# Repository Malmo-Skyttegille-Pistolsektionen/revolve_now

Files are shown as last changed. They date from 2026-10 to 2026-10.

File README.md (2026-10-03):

# Revolve Now

Software for running timed shooting programs on a rotating target system, built
by and for Malmö Skyttegille Pistolsektionen.

An ESP32-S3 board turns the targets face-on and edge-on to a shooting program
and plays the spoken range commands over an amplifier. A React web app — served
by the board itself over WiFi — starts and stops programs, follows the run live
over Server-Sent Events, and manages the stored programs and audio.

<p align="center">
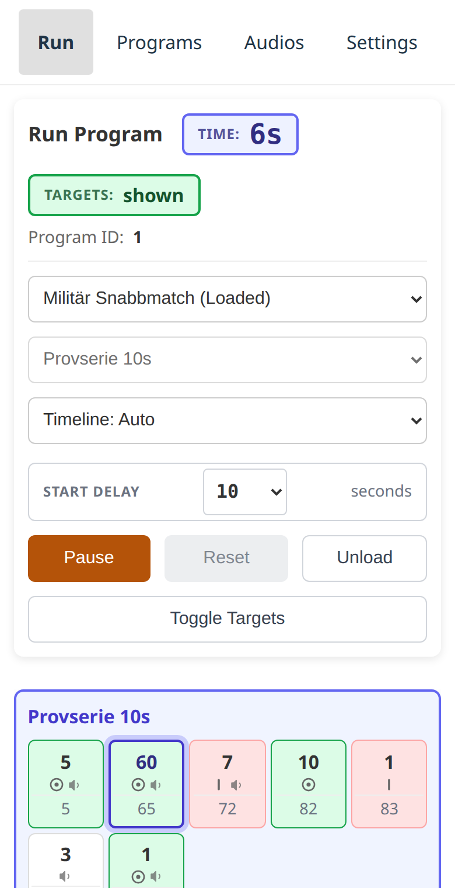
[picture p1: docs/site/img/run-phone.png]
The Run page on a phone, partway through a program
  
</p>

## ⚠️ SAFETY WARNING — READ BEFORE INSTALLING OR OPERATING

**This device moves steel on a live firing range, and it moves it on a timer.**
A target turns because a program said it was time, not because it can see who
is in front of it. It has no idea anyone is downrange.

- **The range's own safety rules and range commands govern the line. This
  software governs nothing.** A program running is not a range that is hot; a
  program stopped is not a range that is safe.
- **NEVER go downrange because the web app says the run has finished.** Confirm
  a cease-fire the way your range already requires — verbally, with firearms
  cleared and benched.
- **NEVER leave the device powered while people are forward of the firing
  line** unless your club has decided that is safe and knows what the targets
  do at power-up.
- **A target turning can injure somebody standing next to it.** Keep clear of
  the mechanism whenever the device is powered.

The targets rest **shown** at boot, deliberately: a target that turns of its own
accord when a board is powered is the failure this project is most concerned
with. That resting state can be changed to suit a target system wired the other
way round, but only over a USB cable, never from the web app — see
[Settings](https://malmo-skyttegille-pistolsektionen.github.io/revolve_now/settings/).

**Do not rely on this software to protect anyone.** It is a convenience for
running programs, not a safety device, and it has no interlock, no sensor, and
no way to know where people are.

**LIABILITY DISCLAIMER:** This project is provided as-is with absolutely no
warranty of any kind. The author(s) accept no responsibility or liability for
any injury, damage, or loss resulting from building, installing, modifying, or
operating this system. You build and use it entirely at your own risk.

---

## Documentation

Everything an operator needs is on the documentation site:

- **[Operator documentation](https://malmo-skyttegille-pistolsektionen.github.io/revolve_now/)**
  — wiring, connecting, running a program, settings, and what the status LED is
  telling you. This is the one to send a club member.
- **[Program editor](https://malmo-skyttegille-pistolsektionen.github.io/revolve_now/editor/)**
  — write and edit programs in a browser with **no device attached**, then
  download the file or open a pull request against this repository. Also useful
  for reading a shipped program without a board in front of you.
- **[Hardware and wiring](https://malmo-skyttegille-pistolsektionen.github.io/revolve_now/hardware/)**
  — what a target system has to do to work, the DB9 pinout, and the transistor
  that does the switching.

## Installing

Releases ship a pre-built firmware image; you do not need a toolchain to put it
on a board. See
[Connecting](https://malmo-skyttegille-pistolsektionen.github.io/revolve_now/connecting/)
for getting the device onto your network afterwards, and
[Settings](https://malmo-skyttegille-pistolsektionen.github.io/revolve_now/settings/)
for adapting a stock image to your own board — the target pin, its polarity,
the audio and LED pins and the device's name are all configurable on the
device, without rebuilding it.

## Target systems

- **[Eigenbrod TP2](https://eigenbrod-schiessanlagen.de/en/products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)**
  — what this was built against and what it runs on.

Nothing in the firmware is specific to that system. The board speaks no
proprietary protocol to the targets: it closes and opens **one circuit**, and
the target system's own electronics do the rest. Any system driven the same way
should work.

## Layout

| Directory | Holds |
|---|---|
| [`contracts/`](contracts/README.md) | The canonical API contract: OpenAPI for REST v2, AsyncAPI for SSE v2, the program schema |
| [`firmware/`](firmware/README.md) | The ESP-IDF firmware: target IO, audio, storage, REST + SSE server |
| [`webapp/`](webapp/README.md) | The React front end, embedded in the firmware's application image |
| [`resources/`](resources/README.md) | Shipped programs and audio clips flashed onto the device |
| [`docs/`](docs/) | The [decision log](docs/DECISIONS.md), [how releases are cut](docs/RELEASING.md), and the source of the documentation site |

## Contributing

Building, flashing, running it without a device, and the coding standards are
in [`CONTRIBUTING.md`](CONTRIBUTING.md).

## License

MIT — see [`LICENSE`](LICENSE). It covers everything here except the vendored
libraries under `firmware/lib/`, which keep their own.

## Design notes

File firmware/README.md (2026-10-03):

# Revolve Now firmware — ESP32 (ESP-IDF)

Native ESP-IDF firmware for Malmö Skyttegille Pistolsektionen's
[Eigenbrod TP2 rotation target system](https://eigenbrod-schiessanlagen.de/en/products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).
It runs shooting programs — turning the targets and playing the commands — and
serves the React webapp over REST and Server-Sent Events.

This is the ESP-IDF port of
[`rotation_target_backend_esp32_micropython`](https://github.com/Malmo-Skyttegille-Pistolsektionen/rotation_target_backend_esp32_micropython)
at its API v2 revision. Both speak the same contract; see
[`docs/adr/0001-esp-idf-port.md`](docs/adr/0001-esp-idf-port.md) for why the
port exists.

## Hardware

**ESP32-S3** with 16 MB flash and 8 MB PSRAM — an ESP32-S3-DevKitC-1 N16R8, or
the club's own REVOLVENOW Rev 1 board.

No pin is hardcoded: the target GPIO **and its polarity**, the status LED, and
the I2S pins are all `menuconfig` options, so a different board is a different
`sdkconfig` rather than a source edit.

See [`docs/HARDWARE.md`](docs/HARDWARE.md) for the wiring, the full option list,
the partition layout, and the esptool `--no-stub` quirk you will hit when
flashing these boards.

## Build, flash, test

```bash
git clone https://github.com/Malmo-Skyttegille-Pistolsektionen/revolve_now.git
cd revolve_now/firmware

idf.py set-target esp32s3          # FIRST clone only - see the warning below
idf.py menuconfig                  # optional: seed WiFi under "Revolve Now"
idf.py build
idf.py -p /dev/ttyACM0 flash monitor
```

> ⚠️ **`idf.py set-target` and `idf.py fullclean` destroy `sdkconfig`** — the
> only copy of the WiFi credentials. Use **`idf.py reconfigure`** on a clone you
> have already built. Why, and how to keep the credentials out of the tree
> entirely, in [`CONTRIBUTING.md`](CONTRIBUTING.md).

> **`idf.py flash` uses esptool's stub loader, which fails on this board** and
> fails in a way that looks like bad flash. See
> [`docs/HARDWARE.md`](docs/HARDWARE.md) for the `--no-stub` invocation.

The shipped audio and programs live in the monorepo's sibling `resources/`
directory. The build reads them from there by default; point `RT_RESOURCES_DIR`
elsewhere to override.

The webapp is embedded in the **application image** when `../webapp/dist`
exists, so run `npm run build` in `webapp/` first — see
[*The seams*](../AGENTS.md#the-seams). Because it rides in the app slot, an OTA
updates it along with the firmware (#227); the shipped audio and programs are
still on the filesystem and still do not.

`idf.py flash` no longer touches what has been uploaded to the device: no image
is built for the `userdata` partition at all (#227), so there is nothing to
write over it. The app slot it writes carries the firmware, the web app and the
shipped audio together.

**`partitions.csv` is not a file to change casually** — a table change cannot
go out over the air and wipes NVS, so it costs a cable pass over every board.
See [*Changing the partition table*](CONTRIBUTING.md#changing-the-partition-table).

### WiFi

Credentials live in **NVS**, not in the firmware, so moving the device to a new
network does not need a rebuild. `idf.py flash` leaves the `nvs` partition
alone, so they also survive a firmware update.

If the device cannot join a network — out of the box, or because the range's
WiFi password changed — it brings up a **setup access point** and a captive
portal instead of sitting there unreachable:

1. Join `revolve-now-setup-XXXX` (password: `CONFIG_RT_SETUP_AP_PASSWORD`,
   default `revolvenow`).
2. A setup page should open automatically; if not, browse to
   `http://192.168.4.1`.
3. Enter the network details. The device saves them and restarts.

The Kconfig `RT_WIFI_SSID`/`RT_WIFI_PASSWORD` values are only a first-boot
seed — leave them at the defaults and use the portal, or set them to skip it.
`sdkconfig` is gitignored either way, the same way the MicroPython backend kept
`wifi_credentials.py` out of git.

Once up, the device is at `http://revolve-now.local` (mDNS) or whatever
address it logs on boot.

### Host tests

The run state machine, the program JSON contract, the `stateUpdate` serializer
and the control lock all run on the build machine — no hardware, no sleeps:

```bash
cd host_test && cmake -B build && cmake --build build -j && cd build && ctest --output-on-failure
```

Add `-DRT_COVERAGE=ON` for gcov/gcovr coverage, or `-DRT_SANITIZE=ON` to build
the suites with ASan + UBSan:

```bash
cd host_test && cmake -B build-san -DRT_SANITIZE=ON && cmake --build build-san -j \
  && cd build-san && ctest --output-on-failure
```

CI runs both the plain and the sanitized build — the sanitizers force `-O1` and
change codegen, so a clean run of one is not evidence about the other. UBSan is
what catches signed-overflow in the duration and id arithmetic, which `-Wall`
cannot see.

Only `IDF_PATH` is needed (for ESP-IDF's copy of Unity), not the cross
toolchain.

### Lint

```bash
pre-commit run --all-files
```

`.clang-format` covers `main/`, `lib/rt_logic/` and `host_test/`. Vendored code
(`lib/psychic_http/`, `lib/arduinojson/`) and the repository's `resources/`
tree are excluded and must stay byte-identical to upstream — never reformat
them.

## API

[`docs/api-v2.md`](docs/api-v2.md) — REST under `/api/v2`, SSE at `/sse/v2`,
plus `GET /api/v2/diagnostics/info` for post-incident triage without a cable.
The canonical machine-readable contract is
[`../contracts/`](../contracts/README.md) — `openapi.yaml` for REST,
`asyncapi.yaml` for SSE, `program.schema.json` for the program document. A
change to any of them lands in the same PR as the firmware change it
describes.

## Layout

See [`docs/ARCHITECTURE.md`](docs/ARCHITECTURE.md) for the task model, the
locking rules and the storage layout.

| Path | Holds |
|---|---|
| `lib/rt_logic/` | Hardware-independent logic — the tested core |
| `lib/psychic_http/`, `lib/arduinojson/` | Vendored third-party |
| `main/` | The firmware: `io/`, `storage/`, `repositories/`, `executor/`, `net/` |
| `host_test/` | Unity suites for `lib/rt_logic/`, plus the CMake + CTest harness |
| `../resources/` | The shipped audio and programs (sibling directory) |

## Documentation

| Document | Covers |
|---|---|
| [`docs/api-v2.md`](docs/api-v2.md) | The REST + SSE contract, shared with the MicroPython backend |
| [`docs/HARDWARE.md`](docs/HARDWARE.md) | Boards, pin configuration, flashing, partitions |
| [`docs/ARCHITECTURE.md`](docs/ARCHITECTURE.md) | Task model, locking, storage layout |
| [`docs/QEMU.md`](docs/QEMU.md) | Running the firmware in the emulator, and what it does not emulate |
| [`docs/adr/0001-esp-idf-port.md`](docs/adr/0001-esp-idf-port.md) | Why this port exists |
| [`CONTRIBUTING.md`](CONTRIBUTING.md) | Workflow, tests, commit conventions |
| [`SECURITY.md`](SECURITY.md) | Threat model and reporting |

## Related

- [Frontend webapp](https://github.com/Malmo-Skyttegille-Pistolsektionen/rotation_target_frontend_webapp)
- [MicroPython backend](https://github.com/Malmo-Skyttegille-Pistolsektionen/rotation_target_backend_esp32_micropython)
- [Resources](https://github.com/Malmo-Skyttegille-Pistolsektionen/rotation_target_backend_resources) — programs, audio, API specs

## License

MIT. See [LICENSE](../LICENSE).

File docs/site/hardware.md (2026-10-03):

# Hardware and wiring

This is what a target system has to be, electrically, before a board can drive
it — the thing a club member setting up a second device needs before anything
else on this site is useful.

## The interface: one circuit

The board does not speak any target system's proprietary protocol. It closes
and opens **one circuit**, over a DB9 connector, and the target system's own
electronics do the rest.

| DB9 pin | Function |
|---|---|
| 2 | Target control — shorted to ground to actuate the target system |
| 5 | Ground — the common return for pin 2 |

Electrically, the board does not close that circuit itself — a GPIO pin
supplies only tens of milliamps and should not meet the target system's
voltage directly. A transistor does the switching instead:

```mermaid
flowchart LR
    subgraph ESP["ESP32-S3"]
        GPIO["GPIO5"]
        GND["GND"]
    end

    R["1 kΩ"]
    Q["BC547B<br/>NPN · 45 V · 100 mA"]

    subgraph TS["Target system (DB9)"]
        P2["pin 2 — target control"]
        P5["pin 5 — ground"]
    end

    GPIO --> R --> Q
    Q -- collector --> P2
    Q -- emitter --> GND
    GND --- P5
```

A GPIO pin drives a 1 kΩ resistor into the base of a **BC547B** NPN
transistor, which does the actual switching. That transistor is rated
**45 V and 100 mA**, and it offers no galvanic isolation. Anything a target
system asks for beyond those limits — a mains-level signal, or an inductive
load like a relay coil — needs a relay or an opto-isolator of its own between
the DB9 connector and the load; it cannot be wired to pin 2 directly.

## What a target system has to do to work

Nothing in the firmware is specific to any one target system — it was built
against the [Eigenbrod TP2](https://eigenbrod-schiessanlagen.de/en/products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), but anything driven
the same way should work.

| Requirement | Why |
|---|---|
| Be actuated by a **contact closure** — two terminals shorted together | That is the entire interface. A system expecting a serial protocol, a proprietary bus or a mains signal needs hardware in between |
| Be **level-driven**, not pulse-driven | The firmware holds the line in one state for the length of an event. A system that toggles on each pulse would move on both edges |
| Have **two positions** — face-on and edge-on | The program vocabulary is show and hide. There is no intermediate angle to command |
| Take **one control line per group of targets you want to move together** | Each line is a *bank*. A bank is one contact closure and moves as one; a device drives up to eight |
| Be safe sitting **face-on** with no power | The targets rest face-on and stay there at boot, deliberately: somebody may be downrange when a board is powered, and a target that turns on its own can injure them |

## Target banks

A **bank** is one control line: one GPIO, one transistor, one DB9 circuit,
moving every target wired to it together. A device drives between one and
eight of them, lettered by position — **A, B, C…** — and A is the one the
diagram above shows. A club with one line of targets has bank A and nothing
else, which is what every device shipped so far is.

Banks exist so a range can be exposed a lane at a time: three lanes on three
banks can be shown one after another from a single program, where one line can
only turn all three at once.

Each bank is separate hardware. It needs **its own GPIO** and its own
transistor, and it carries **its own polarity** — whether a low level shows it —
because the resting state that has to be safe is a property of that bank's
wiring, not of the device. Adding one is therefore soldering first and
configuration second: wire the line, then add the bank in
[Expert mode](expert-mode.md) with the pin you wired it to, a name your
operators will recognise (`Vänster`, `Bana 3`), and the polarity that leaves it
resting where it should. The device adopts a new bank at its next restart.

Where the targets rest at boot is **one setting for every bank**, changed on
the serial console only: it protects somebody standing downrange, and that is
not a per-bank question.

Which level shows the targets, and the rest of the pin assignment, is a
configuration setting rather than a build setting now — but it is still decided
when a device is set up, not per range day. Full wiring detail, including the
supported boards and their `menuconfig` options, is in
[`firmware/docs/HARDWARE.md`](https://github.com/Malmo-Skyttegille-Pistolsektionen/revolve_now/blob/main/firmware/docs/HARDWARE.md)
in the repository.

**Optional peripherals**, each independently switchable off at build time: the
audio DAC that plays the range commands, and the [status LED](status-led.md).
A target that only turns, with no audio, is a supported configuration.

<!-- TODO: a photograph of the DB9 connector and the transistor as actually wired -->

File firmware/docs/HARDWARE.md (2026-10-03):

# Hardware

## Supported boards

The firmware targets **ESP32-S3** with 16 MB flash and 8 MB PSRAM. Two boards
are in use:

| Board | Module | Notes |
|---|---|---|
| ESP32-S3-DevKitC-1 N16R8 | ESP32-S3-WROOM-1 N16R8 | Development board. Has an onboard WS2812 on GPIO48. |
| REVOLVENOW Rev 1 | ESP32-S3-WROOM-1 N16R8 | The club's own board (open source hardware). Trigger outputs with selectable 3.3 / 5 / 12 V rails, Ethernet section, hand-fitted PCM5102A audio breakout on the Rev 1 prototypes. No onboard WS2812. |

Confirmed against real silicon with `esptool flash-id`: ESP32-S3 (QFN56)
rev v0.2, 16 MB **quad** flash at 3.3 V, embedded **8 MB octal** PSRAM. The
"flash type: quad" the eFuse reports is about the flash only — the R8's PSRAM
is octal, which is why `sdkconfig.defaults` sets `CONFIG_SPIRAM_MODE_OCT`.
Getting that backwards leaves PSRAM undetected at boot rather than failing
loudly.

## Configuration

**No pin is hardcoded.** Everything is a `menuconfig` option under
**Revolve Now → Hardware**, so a different board is a different
`sdkconfig`, not a source edit.

| Option | Default | Meaning |
|---|---|---|
| `RT_TARGET_GPIO` | 5 | Drives the transistor that turns **bank A** |
| `RT_TARGET_ACTIVE_LOW` | y | Whether **low** shows bank A |
| `RT_RGB_LED_ENABLED` | y | Board has an addressable WS2812 |
| `RT_RGB_LED_GPIO` | 48 | Its pin |
| `RT_AUDIO_ENABLED` | y | Board has an I2S DAC |
| `RT_I2S_PORT` | 0 | I2S peripheral number |
| `RT_I2S_BCK_GPIO` | 10 | Bit clock |
| `RT_I2S_WS_GPIO` | 12 | Word select (LRCK) |
| `RT_I2S_DOUT_GPIO` | 11 | Data out → the DAC's DIN |

Defaults are the wiring the MicroPython backend used on this hardware
(`src/backend/config.py` in that repository). Note its "ESP32-C6" comments are
stale — the pin numbers beside them are correct, the chip name is not.

> ⚠️ **`RT_TARGET_ACTIVE_LOW` is a safety setting, not a preference.** It says
> which level *shows* the targets. On the prototype the GPIO drives a BC547B
> whose low state opens the connection. A board that buffers, inverts, or
> switches a relay directly needs it off — and if it is wrong, the boot state in
> `targets::init()` is inverted, so the targets face away when they should be
> face-on (D-31).

### Target banks

A device drives 1 to 8 banks, called **A** to **H** (D-41). Kconfig seeds bank A
only — a second bank is something a device is *told about*, over the API or the
serial console, and it lives in NVS beside the rest of the hardware
configuration. Every bank has its own pin, its own polarity and a display name.

| Bank | Suggested pin | Note |
|---|---|---|
| A | 5 | The stock target pin; `RT_TARGET_GPIO` |
| B–H | 6, 7, 8, 9, 13, 14, 15 | Adjacent on the DevKitC-1 header, all free |

Nothing forces those seven — any pin the validator accepts will do. They are
listed because they are contiguous on the header and none of them clashes with
the stock LED or I2S wiring.

### Pins the configuration refuses

`rt::validate()` refuses these outright rather than warning, because the
recovery from getting one wrong is a USB cable and a reflash.

| Pins | Why |
|---|---|
| 0, 3, 45 | Strapping — latched at reset; the board simply does not come up |
| 19, 20 | USB Serial/JTAG D-/D+ — the recovery path |
| 22–25 | Absent from the ESP32-S3 package |
| 26–32 | In-package SPI flash and PSRAM |
| **35–37** | The **octal** PSRAM's extra data lines on the N16R8 |
| **43, 44** | UART0 — the serial console |
| 46 | Input-only on many modules, so it cannot drive anything |

35–37 are the ones to know about; D-41 records why they were missed. That
leaves 22 output-capable pins after the stock five (target 5, LED 48, I2S
10/11/12) — comfortably more than eight banks need.

Disabling `RT_RGB_LED_ENABLED` or `RT_AUDIO_ENABLED` compiles the driver out
entirely rather than failing at runtime. A target that only turns, with no
audio, is a supported configuration: programs still run and the API still lists
clips, they simply do not play.

## Wiring (prototype)

| ESP32 pin | Connects to | Function |
|---|---|---|
| GPIO5 | DB9 pin 2, via 1 kΩ into a BC547B | Target control (bank A) |
| GND | DB9 pin 5 | Common ground |
| GPIO10 / GPIO12 / GPIO11 | PCM5102A BCK / LRCK / DIN | I2S audio |
| GPIO48 | onboard WS2812 (devkit only) | Status LED |

```mermaid
flowchart LR
    subgraph ESP["ESP32-S3"]
        GPIO["GPIO5"]
        GND["GND"]
    end

    R["1 kΩ"]
    Q["BC547B<br/>NPN · 45 V · 100 mA"]

    subgraph TS["Target system (DB9)"]
        P2["pin 2 — target control"]
        P5["pin 5 — ground"]
    end

    GPIO --> R --> Q
    Q -- collector --> P2
    Q -- emitter --> GND
    GND --- P5
```

The status LED, where fitted: **blinking red** while joining a network, **solid
red** once it has given up, **yellow** on the network but not serving yet,
**green** serving, **blue** on the setup portal's own access point. Yellow is
milliseconds wide on a healthy boot, so a device sitting on it means the network
is fine and the HTTP server is not.

## Flashing

### Large reads need `--no-stub`

**esptool's stub fails on `read-flash` above roughly 3 MB per transfer.** It
dies with `Packet content transfer stopped`. Measured on the DevKitC-1 over the
native USB port, esptool 5.3.1, reading from `0x0`:

| Transfer | Stub | Result |
|---|---|---|
| 1 MB | yes | works |
| 2 MB | yes | works |
| 3 MB | yes | works |
| 4 MB | yes | **fails** |
| 8 MB | yes | **fails** |
| 16 MB | yes | **fails** |
| 16 MB | `--no-stub` | works |

It is the *size* that decides it, not the address: where it dies is wherever
the transfer had got to. The threshold sits between 3 MB and 4 MB.

**The stub does not return bad data — it fails, or it is correct.** A 1 MB stub
read was compared byte for byte against the same range of a `--no-stub` dump of
the whole chip. The only differences were inside `nvs`, because esptool resets
the board between reads and the firmware writes NVS on boot. Everything else
matched exactly.

**So most work does not need `--no-stub`,** and the stub is roughly 15x faster
(1 MB in 5.9 s). Reach for it when reading at full-flash scale — taking a
backup image of a board, for instance:

```bash
esptool --port /dev/ttyACM0 --no-stub --baud 921600 \
  read-flash 0x0 0x1000000 flash_full_16MB.bin
```

**Writes are a separate question and are not covered by the numbers above.**
`write-flash` with the stub was measured good at 1.1 MB and at 10 MB on
2026-08-24, hash-verified, so `idf.py flash` is fine. A full 16 MB write with
the stub has not been tested. Until it is, a restore of a whole-chip image is
the one write worth doing with `--no-stub`, on the grounds that it runs when
something has already gone wrong.

```bash
# flash arguments are printed at the end of `idf.py build`
python -m esptool --chip esp32s3 --port /dev/ttyACM0 \
  --before default-reset --after hard-reset \
  write-flash --flash-mode dio --flash-freq 80m --flash-size 16MB \
  0x0 build/bootloader/bootloader.bin \
  0x8000 build/partition_table/partition-table.bin \
  0x1d000 build/ota_data_initial.bin \
  0x20000 build/revolve_now.bin
```

**A failed large read presents exactly like a bad flash sector and is not one.**
Running the same read with and without `--no-stub` is the test that tells them
apart; chasing it as failing hardware, or as a cable problem, wastes a lot of
time.

> **This section has been wrong before.** It previously claimed the threshold
> was "about 256 KB" and that 512 KB and 1 MB reads failed — they do not. The
> rule survived unexamined because "always pass `--no-stub`" was cheap to obey,
> so nobody re-derived it. If you change these numbers, say what you measured
> and when.

### Ports

The boards expose two USB-C sockets. The **native USB-Serial/JTAG** one is USB
vendor `303a`; the **UART bridge** is `10c4` (CP2102) or `1a86` (CH343).

**Both can enumerate as `/dev/ttyACM*`** — the CH343 is a CDC device too — so
the device name does not tell them apart. The vendor does:

```bash
udevadm info -q property -n /dev/ttyACM0 | grep ID_VENDOR_ID
# 303a = native USB-Serial/JTAG
# 1a86 / 10c4 = UART bridge
```

**Which socket matters, and not symmetrically:**

| | native USB (`303a`) | UART bridge (`1a86`/`10c4`) |
|---|---|---|
| `ESP_LOG` output | yes | yes |
| **The interactive console** | **yes** | **no** |
| Flashing | yes | yes |
| Large `read-flash` | needs `--no-stub` | fine |

The console is the asymmetric one and it catches people out. `console.cpp`
writes with `usb_serial_jtag_write_bytes()`, so **the `rt>` prompt exists only
on the native USB socket.** On the UART bridge the log output still streams,
which makes the port look right — but every command typed there is silently
ignored. That covers `boot-targets` (#144), `wifi-scan` and `wifi-info`.

If a documented serial-only command appears to do nothing, check the vendor ID
before checking anything else.

With two boards connected, tell them apart by MAC — the kernel puts it in the
device name:

```
/dev/serial/by-id/usb-Espressif_USB_JTAG_serial_debug_unit_30:ED:A0:A8:AB:78-if00
```

While a board still runs MicroPython, its firmware claims the USB CDC endpoint
after every hard reset, so back-to-back esptool invocations are less reliable
than one long call; `--before no-reset --after no-reset` holds it in the
bootloader. This firmware does not use native USB and does not do that.

### Reflashing keeps uploaded programs and audio

No image is flashed into the `userdata` partition (#227), so `idf.py flash`
leaves anything a club uploaded alone. The `nvs` partition survives too, so the
WiFi credentials and the hardware configuration outlive a reflash.

## Partitions

16 MB, laid out in [`partitions.csv`](../partitions.csv), whose comments say
what each partition holds and why it is the size it is. In short: two
app slots, each carrying the firmware, the web app and the shipped audio and
programs; `userdata` for uploads, which no update path writes; `nvs` for
settings. `POST /api/v2/ota` writes the inactive slot, and rollback is enabled.

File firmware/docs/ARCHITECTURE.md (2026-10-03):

# Architecture

## The split: `lib/rt_logic` is the tested core, `main/` is the firmware

Everything that decides *what should happen* lives in `lib/rt_logic/`, is free
of ESP-IDF and hardware, and is covered by the Unity suites in `host_test/`.
`main/` is the part that talks to the chip and the network.

| Layer | Holds |
|---|---|
| `lib/rt_logic/` | Program model + JSON (`program.*`), run state + `stateUpdate` serializer (`program_state.h`), run-position maths (`run_position.h`), the run state machine (`executor.*`), the control lock (`control_lock.h`), target banks (`target_bank.h`), WAV header parsing (`wav_header.*`), URI path ids (`uri_path.h`) |
| `main/io/` | `targets` (one GPIO per bank), `audio` (I2S WAV playback), `rgb_led` |
| `main/storage/` | LittleFS mount and directory helpers |
| `main/repositories/` | `programs`, `audios` — what is on the filesystem |
| `main/executor/` | The run-loop task and the real clock/effects behind `rt::Executor` |
| `main/net/` | `wifi_mgr`, `wifi_store` (NVS credentials), `setup_portal` (SoftAP fallback), `web_server` (REST), `sse_hub` (SSE: state, heartbeat, issues) |
| `lib/psychic_http/`, `lib/arduinojson/`, `lib/dns_server/` | Vendored third-party, never reformatted |

`rt::Executor` takes a `rt::Clock` and a `rt::Effects` by reference. The
firmware supplies `esp_timer_get_time()` and the real target/audio/SSE
side effects; the host tests supply a clock they advance by hand and an
effects recorder. That is what lets the whole run state machine — including
the exact `stateUpdate` sequence a client sees for a full series — be asserted
on the build machine with no sleeps and no hardware.

### Every parser belongs in `rt_logic`

**If it takes bytes from outside the device and turns them into meaning, it goes
in `rt_logic`, not `main/`.** That covers the WAV header (`wav_header.*`), URI
path ids (`uri_path.h`), program documents and program filenames (`program.*`).

This is not tidiness. Those parsers are the attacker-reachable surface — an
uploaded WAV, a URI, an uploaded program — and in `main/` they sit behind a
`FILE*` or an HTTP request in an anonymous namespace, where no host test can
reach them and neither ASan nor UBSan ever sees them. In `rt_logic` they are
covered by `host_test/` and run under both sanitizers in CI on every push.

`wav_header.h` shows the shape: it takes a `ByteSource` (absolute `uint64_t`
offsets) rather than a `FILE*`. The firmware adapts stdio to it in
`main/io/audio.cpp`; the tests adapt a `std::vector`. The abstraction also
makes a whole bug class unrepresentable — the relative-seek form it replaced
could seek *backwards* on a crafted chunk size and loop forever.

## Concurrency

Three tasks touch run state:

- **`run_loop`** (priority 4, `main/executor/program_executor.cpp`) — calls
  `rt::Executor::tick()`, then waits for however long `tick()` asked, or until
  a control call notifies it. `tick()` returns at most 200 ms
  (`rt::kMaxSleepMs`), so `stop` takes effect promptly even mid-event.
- **`httpd`** — REST handlers, calling the same `executor::` functions.
- **`audio`** (priority 5) — plays queued clips. Above the run loop
  deliberately: an underrun is audible on the range, a few ms of added REST
  latency is not.

A single recursive mutex guards `rt::ProgramState` and the executor. It is
recursive because `set_targets()` is reached both directly (the `/targets/*`
endpoints) and from inside the executor's own locked section.

**Target state is per bank** (D-41). `ProgramState::bank_shown` is one flag per
bank in letter order, sized at `executor::init()` from `targets::count()`;
`rt::Effects::set_targets()` takes a bank mask, and `rt::kAllBanksMask` is what
both an event's `command` and the `/targets/*` endpoints use. `targetBanks` on
the wire is one key per bank and the only thing the wire says about them.

**SSE never waits on a client.** `rt::Effects::state_changed()` only sets a
flag; `flush()` serializes the state and hands it to `sse_hub` under the lock,
so snapshot order is send order, and the run loop never touches a socket. The
frame waits in `rt::SseOutbox`, where a newer `stateUpdate` supersedes a
pending one, and a single drain message wakes the httpd task (#427). That task
then sends it, and since it serves REST too, a client whose socket cannot take
a whole frame is closed rather than waited for (`rt::SseClients`, #343).

## Storage

Two filesystems, and the split is the point (#227, D-35/D-37).

```
/embedded/audio/     audios.json + 77 ADPCM WAVs   read-only, in the app image
/embedded/programs/  <id>.json                     read-only, in the app image
/embedded/webapp/    the built frontend            read-only, in the app image
/userdata/audio/     audios.json + WAVs            writable, `userdata` partition
/userdata/programs/  <id>.json                     writable, `userdata` partition
```

**`/embedded` is not a partition.** It is `.rodata` in the application binary,
exposed as a read-only VFS (`main/storage/embedded_fs.cpp`) so that every
reader keeps using `fopen`/`stat`/`opendir`. An OTA replaces it along with the
firmware, which is what makes one image one update; `open()` for writing
returns `EROFS`, so nothing can modify it even by mistake.

**`/userdata` (6.75 MB LittleFS) holds uploads and nothing else**, and **no
update path writes it** — no image is built for that partition at all, so even
`idf.py flash` leaves uploads alone. It is formatted on first mount.

**Read-only is a property of the directory, not the document.** A program's
`readonly` flag is imposed by the loader from where the file came from, never
read from the file — an uploader must not be able to claim its program is
shipped and thereby undeletable. `host_test/test_program_json` asserts this.

**Shipped and uploaded ids are two disjoint ranges, not one shared space
(#129).** `kFirstUploadId` (`main/config.h`) is where `add_uploaded()` starts
assigning; every shipped id must sit below it —
`resources/programs/validate_programs.sh` enforces that on the program side.
Both `programs::load_all()` and `audios::load_all()` load the shipped
directory first, so if the ranges were ever violated an uploaded id landing on
a shipped one would silently win the collision — the shipped copy is what the
loader keeps instead, logging the collision and raising a
`program_id_collision`/`audio_id_collision` `backend_issue` (into
`startupIssues`, since this can only be discovered before the server exists).
`lib/rt_logic/id_range.h` is the host-tested logic behind both the id
assignment and the collision check.

The filename is the authority on a program's id, not the `id` field inside it;
that is what keeps delete (which removes `<id>.json`) consistent with the
in-memory store.

Programs are held in a `std::map`, not an `unordered_map`: `ProgramState` holds
a bare `const rt::Program *` at whatever is loaded, and reference stability
across inserts is what keeps it from dangling.

## Getting on the network

Credentials come from NVS, falling back to the Kconfig seed values. The retry
budget (`CONFIG_RT_WIFI_MAX_RETRIES`) bounds the **initial** association only —
once joined, reconnection is unbounded, because a device that gave up mid-session
would sit powered on and unreachable until someone walked to it.

If the initial join fails, `setup_portal::run()` takes over: a SoftAP, a
wildcard DNS responder (`lib/dns_server/`) so captive-portal probes land on the
setup page, and a form that writes credentials to NVS and reboots. It runs its
own minimal `esp_http_server` rather than the API server — nothing else on the
device is meaningful in that state, and keeping them apart means no API route
can ever be exposed on an open setup AP.

## Boot order

`app_main()` brings things up in dependency order — NVS, LED, target GPIO,
storage, repositories, audio, executor, WiFi, HTTP server — and reboots rather
than coming up degraded if storage or the network is unavailable. A device on a
range that looks healthy but serves nothing is worse than one that restarts.

Each bank's pin powers up **low**, which on the stock active-low wiring is the
*shown* position. `targets::init()` writes the resting level into the output
latch *before* `gpio_config()` enables the driver, per bank, so no pin ever
presents an intermediate level; `executor::init()` then adopts that state rather
than picking its own, so the hardware matches the first `stateUpdate` a client
receives without an edge in between (D-31, #145).

## Relationship to the MicroPython backend

This is a port of `rotation_target_backend_esp32_micropython` at its
"SSE-first API v2" revision, route for route and semantic for semantic. Where
behaviour is subtle, the host tests name the MicroPython test they came from.
Both backends are meant to be interchangeable from the webapp's point of view;
`docs/api-v2.md` is the contract that has to stay true of both.

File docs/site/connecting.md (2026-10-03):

# Connecting

The board serves its own web app — there is nothing to install. But you can
only open it once the device is **on a network you are also on**, so that comes
first.

## Start with the LED

The [status LED](status-led.md) tells you which of two situations you are in,
before you try any address:

| LED | Situation | Go to |
|---|---|---|
| **Green** | On a network and serving | [Finding the device](#finding-the-device) |
| **Blinking red** | Still trying to join | Wait — it blinks once per attempt, about every 2.4 s |
| **Blue** | Gave up, and is now offering its own network | [The setup portal](#the-setup-portal) |
| **Solid red** | Out of attempts and not offering one either | See [Troubleshooting](troubleshooting.md) |

A device that has never been configured, or that has been moved to a site whose
WiFi it does not know, comes up **blue**. There is no address to find yet — the
network it should join does not exist from its point of view.

## The setup portal

A **blue** LED means the device is running a small access point of its own. Its
name follows the pattern `revolve-now-setup-XXXX`, where `XXXX` is unique to
that device, so two boards on the same site can be told apart.

Join that network from a phone or tablet. It is normally password-protected —
ask whoever set the device up if joining does not prompt for one. Once joined, a
captive-portal page should open by itself; if it does not, browse to
`http://192.168.4.1`.

The setup portal, as it appears on a phone that has joined the device's own network

Enter the network name and password the device should use.

!!! important "Press the button on the device before saving"

    The device will not accept network details until somebody presses its
    **BOOT** button — the small button next to the USB sockets, marked `BOOT` or
    `FLASH` on some boards. Press it, then press **Save and restart**.

    If you save without pressing it first, the page says so and nothing is
    stored; press the button and save again.

    **Why:** the setup network's password is the same on every device and this
    project's source is public, so being *on* that network does not prove much.
    Pressing the button proves somebody is standing at the device — which is
    exactly what cannot be done from a car park. Without it, anyone in radio
    range of a device that has lost its network could point it at a network of
    their choosing.

    The press is good for about a minute, so there is no rush, and a press
    nobody remembers making cannot authorise anything later.

Once saved, the device restarts and joins that network the normal way — the LED
goes blinking red, then green.

From here it is on your network, and the rest of this page applies.

## Moving the device to a different network

If the device can no longer reach the network it knows — the club changed its
WiFi, or the board has been taken somewhere else — it gives up after about ten
seconds and raises the setup portal by itself. Nothing to do: wait for **blue**
and [configure it from there](#the-setup-portal).

The other case is: **the network it knows still exists, and you want it on a
different one anyway.** The device joins ours quite happily and never offers
the portal, so there is nothing to configure it through.

For that, use [Expert mode](expert-mode.md#wifi) — press the device's BOOT
button three times within ten seconds, and the web app offers the same form the
setup portal does. Saving stores the network; the device moves onto it when you
press [**Restart to apply**](expert-mode.md#restart-to-apply), and keeps
everything else: its programs, its clips, and its hardware settings.

**The ten-second hold below is the bigger hammer**, and it is now needed only
for handing a board to another club, or for a board that has to forget the
network built into its firmware. It throws away more than the network.

To do that, **hold the BOOT button for ten seconds**.

| While you hold | LED | Meaning |
|---|---|---|
| 0–3 seconds | unchanged | Nothing has happened yet |
| after 3 seconds | **white** | It is counting. Let go now and nothing is changed |
| after 10 seconds | restarts | Done |

It comes back up **blue**, offering its setup portal, exactly like a board that
has never been configured.

!!! warning "What a ten-second hold erases"

    - **Every network it knows**, including the one built into its firmware —
      which is the point, otherwise it would simply rejoin ours.
    - **Its hardware settings**: pin numbers, hostname and display name go back
      to the defaults, so it will answer to `revolve-now.local` again.

    **Your programs and audio clips are kept.** Anything uploaded to the device
    stays on it, including through a change of owner — that is a separate thing
    from which network it is on, and it may be the only copy.

If you have a USB cable and a serial terminal, `factory-reset` at the device's
console does the same thing and says what it is about to do first.

## Finding the device

Join the same WiFi the device is on, then open its address.

It advertises itself over mDNS, so on most phones, tablets and laptops the
address is just its hostname:

```
http://revolve-now.local
```

!!! note "Used to be `rotation-target.local`"

    The system was called Rotation Target before it became Revolve Now. A
    device still running firmware from then answers at
    `http://rotation-target.local`, and its setup network is
    `rotation-target-setup-XXXX`. It changes to the new name with its next
    firmware update, unless somebody gave it a hostname of its own in Expert
    mode.

If that name does not resolve — some routers and most guest networks block
mDNS — find the device's IP address instead, for example from the router's
client list, and open `http://<that address>` directly. The address is also
shown on the app's own Settings page, beside the server URL, which is the
easiest way to read it out to somebody else once you are in.

The app opens on the Run page:

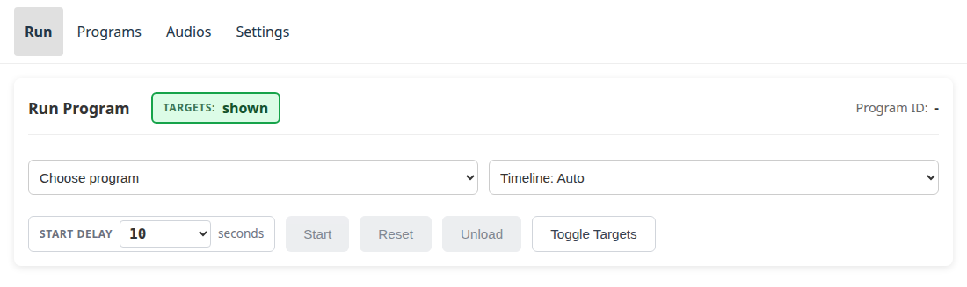
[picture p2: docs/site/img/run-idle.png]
The Run page with nothing loaded


## Editing programs without a device

Programs can also be written on a laptop with no board involved at all, using
the [program editor on the web](https://malmo-skyttegille-pistolsektionen.github.io/revolve_now/editor/)
— see [Writing your own program](writing-a-program.md).

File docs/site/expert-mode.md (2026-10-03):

# Expert mode

Everything that can stop the device working lives here, and nothing else does.

Most clubs never open this page. The settings on it are the ones set once, when
a board is first put together or moved somewhere new — and getting one wrong
does not produce a warning, it produces a device that no longer answers.

## Getting in

**Press the BOOT button on the device three times within ten seconds.** It is
next to the USB sockets and may be marked `FLASH`. An **Expert mode** tab
appears in the web app and stays for five minutes; press three times again for
a fresh five.

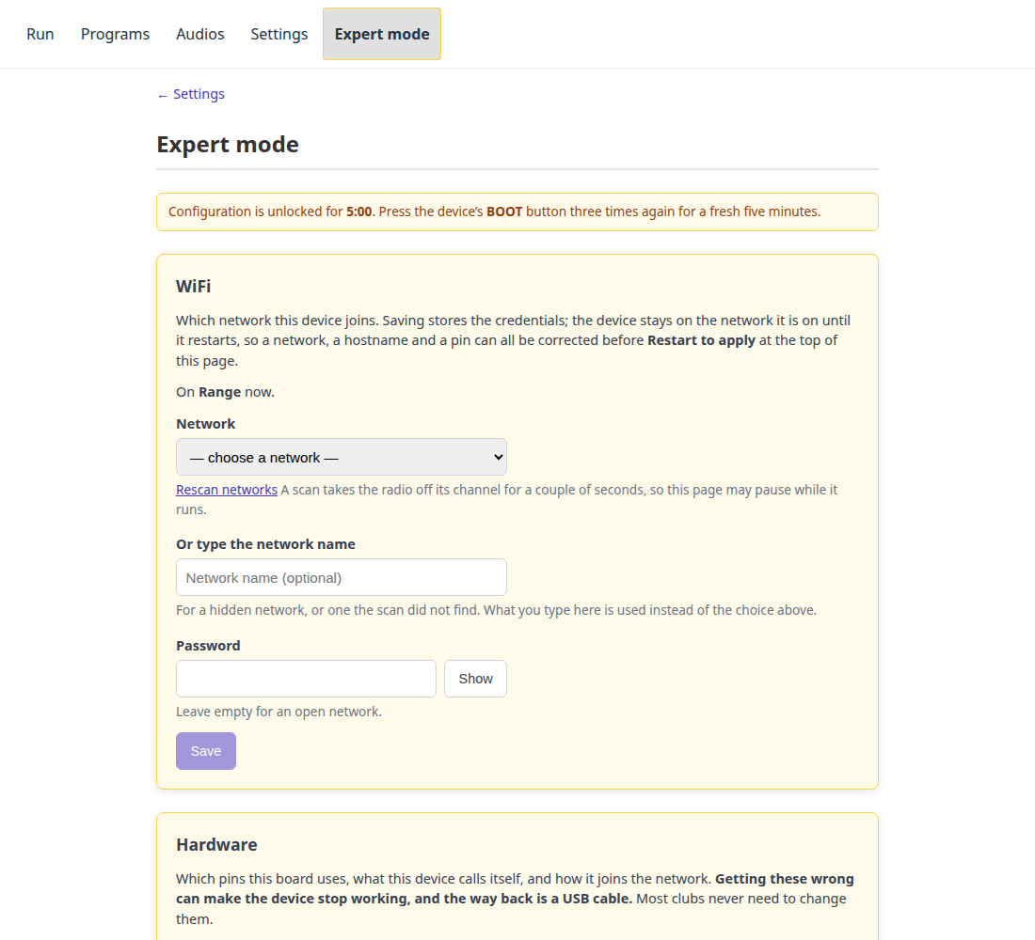
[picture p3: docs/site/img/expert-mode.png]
The Expert mode page, with the configuration window open


Three presses rather than one so it cannot happen by accident, and a button
rather than a password because the thing being established is that **somebody
is standing at the device**. That is not something anyone can do from across
the range, at any distance, with any credential — which is the whole point.

!!! note "It will not open during a run"

    A program that is running holds the window shut. Reconfiguring the machine
    and operating it are different jobs, and these settings only take effect
    when the device restarts anyway. Stop the run first.

If the tab is not there, nobody has pressed the button recently. If it vanishes
while you are typing, the five minutes ran out — press three times again and
carry on.

## Restart to apply

**Nothing on this page takes effect until the device restarts**, and nothing on
it restarts the device by itself. Each section has a plain **Save**, which
stores the change; the device carries on doing what it was doing.

**Restart to apply** appears beside the *Expert mode* heading whenever the
device is holding a setting it is not yet running, and applying everything is
one press of it. So a pin, the hostname and the network can all be corrected in
the same sitting, and the device goes down once instead of three times.

!!! note "The page loses contact while it restarts"

    A few seconds, then reload. If a network change was among what you saved,
    reload at the device's name on the *new* network — and if it cannot join
    that one, it raises its own setup network (`…-setup-XXXX`) and waits there,
    which is [the way back](connecting.md#the-setup-portal) rather than a fault.

The button stays after the five-minute window lapses, and the sections do not:
what the window authorises is the *change*, and this only applies one already
made. **Settings** says the same thing in one line, so somebody who did not make
the change still finds out about it.

It will not restart during a run. Stop the program first.

## WiFi

Which network the device joins. The same form as
[the setup portal](connecting.md#the-setup-portal), because it is the same job:
pick a network from the list, or type the name of one the scan did not find,
and give the password.

**This is the answer to "the network it knows still exists, but I want it
somewhere else."** Before this existed, the only way was to erase everything
the device knew and let it fall back to its setup portal — see
[moving the device](connecting.md#moving-the-device-to-a-different-network),
which is still the route when the board cannot reach *any* network it knows.

**Save** stores the network and nothing more: the device stays on the network
this page is served over, so a mistake here is still fixable from the page that
made it. It moves when you press **Restart to apply**, which is where the
warning above about losing contact applies.

Nothing you have uploaded is affected. Programs and clips are a separate thing
from which network the device is on.

**Rescan networks** runs a fresh scan. It takes a couple of seconds during
which the device's radio is off its own channel, so the page may pause — that
is the scan, not a fault.

**For a hidden network**, leave the list alone and type the name. A hidden
network never appears in a scan, so the list cannot offer it.

## Hardware

Which pins this board uses, what it calls itself, and how it joins the network.
Wrong values here are the ones whose way back is a USB cable:

- A **wrong pin** drives nothing, and one of the pins the device refuses would
  stop it booting at all — which is why it refuses them.
- A **wrong hostname** changes the name the device answers to, so the web app
  stops being reachable at `revolve-now.local`. Worse than a wrong pin,
  which at least leaves the app up to fix it from.

**Nothing here takes effect until the device restarts**, and the page says so
when a saved value is not yet in use — then **Restart to apply** at the top of
the page. A change that appears to have done nothing is how somebody ends up
reflashing a working device.

### The target banks

**Targets** is a table, one row per [bank](hardware.md#target-banks) — one
control line each, lettered by position:

| Column | What it is |
|---|---|
| **Bank** | The letter, A first. It is the row's position, not a stored value, so removing a bank re-letters the ones after it |
| **Name** | What operators see on the Run page — `Vänster`, `Bana 3`. Display only, at most 16 characters, and may be left empty |
| **GPIO** | The pin this bank's transistor is wired to. Every bank needs its own, distinct from the LED's and the three audio pins |
| **Shown when low** | Whether a low level shows *this* bank. Per bank, because the resting state that has to be safe is a property of that bank's wiring |
| **Pad now** | The level actually on the pin, read back rather than remembered. It answers "is the firmware driving this" without a multimeter |

**Add bank B** appends the next letter, up to eight — the most this firmware
drives. A new row starts with **no GPIO**; Save waits until every row has one,
because GPIO 0 is a pin the device refuses and a row cannot be left holding a
value that would come back an error.

Only the **last** bank can be removed, and **bank A never can**: the letter is
the position, so removing B on a four-bank device would silently re-aim C and D
at the wrong lanes. Remove them from the end and add them back.

A row whose values differ from the compiled defaults is marked **changed**, the
same way every other setting on this page is, so **Reset to defaults** says
what it would undo.

A bank you add is only configuration; the line still has to be wired, and the
device adopts the new count when it restarts.

**Where the targets rest at boot** is shown but not editable, and it is **one
setting for every bank**. Which position is safe at rest is a property of the
target system, so it has to be configurable — but it is also what protects
somebody standing downrange when a board is powered, so it changes only from
the serial console with a cable attached.

## Troubleshooting

One zip file holding the device's own details and, if it has crashed, the crash
dump — the thing to attach to a message when a board has come back from a range
day behaving oddly.

!!! warning "A crash dump can contain the WiFi password"

    It is a copy of the device's memory at the moment it failed. Send it to
    somebody you would tell the password to.

That is why it is behind the button press, and it is *only* behind the button
press: [the control lock](settings.md#control-lock) does not block it. Collecting a
fault report is a read, it interferes with nobody, and the person most likely
to want one during a competition is whoever is not driving.

[Sending a fault report](troubleshooting.md#sending-a-fault-report) has the
steps.

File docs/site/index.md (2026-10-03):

# Revolve Now

Software for running timed shooting programs on a rotating target system, built
by and for Malmö Skyttegille Pistolsektionen.

An ESP32-S3 board turns the targets face-on and edge-on to a shooting program
and plays the spoken range commands over an amplifier. A React web app — served
by the board itself over WiFi — starts and stops programs, follows the run live,
and manages the stored programs and audio.

The board does not speak any target system's proprietary protocol: it closes
and opens one circuit, and the target system's own electronics do the rest.
It was built against the [Eigenbrod TP2](https://eigenbrod-schiessanlagen.de/en/products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), but
anything driven the same way — a contact closure, level-driven, two positions —
should work.

!!! danger "Safety warning — read before installing or operating"

    **This device moves steel on a live firing range, and it moves it on a
    timer.** A target turns because a program said it was time, not because it
    can see who is in front of it. It has no idea anyone is downrange.

    - **The range's own safety rules and range commands govern the line. This
      software governs nothing.** A program running is not a range that is hot;
      a program stopped is not a range that is safe.
    - **Never go downrange because the web app says the run has finished.**
      Confirm a cease-fire the way your range already requires — verbally, with
      firearms cleared and benched.
    - **A target turning can injure somebody standing next to it.** Keep clear
      of the mechanism whenever the device is powered.

    **Do not rely on this software to protect anyone.** It is a convenience for
    running programs, not a safety device: no interlock, no sensor, and no way
    to know where people are.

    This project is provided as-is with no warranty of any kind. The authors
    accept no responsibility or liability for any injury, damage or loss
    resulting from building, installing, modifying or operating this system.

The targets rest face-on and stay there at boot by design: somebody may be
downrange when a board is powered, and a target that turns on its own can
injure them. That resting state can be changed to suit a target system wired
the other way round, but only over a serial cable — see [Settings](settings.md).

## Where to start

- [Hardware and wiring](hardware.md) — the DB9 connector and what a target
  system has to be to work with the board.
- [Connecting](connecting.md) — join the device's network and open the web app.
- [Running a program](running-a-program.md) — start, follow, and stop a run.
- [Status LED](status-led.md) — what the device is telling you when nobody has
  a browser open.
- [Troubleshooting](troubleshooting.md) — common problems and what to check.

## Program editor

[**Open the program editor**](editor/){ .md-button } — write and edit programs
in a browser with **no device attached**, then download the file or open a pull
request. Also the easiest way to read a shipped program without a board in
front of you.

## Write a program without a device

The **[program editor](https://malmo-skyttegille-pistolsektionen.github.io/revolve_now/editor/)** runs entirely in a browser tab, with no board
attached. Open a program from this repository, edit it, and either download the
file or open a pull request with it. [Writing your own
program](writing-a-program.md) walks through building one from nothing.

## Source

Full technical documentation — hardware wiring, the API contract, and the
firmware and web app internals — lives in the
[repository](https://github.com/Malmo-Skyttegille-Pistolsektionen/revolve_now).

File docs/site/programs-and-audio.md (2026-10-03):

# Programs and audio

Everything the device runs is stored on the device: the programs, and the
spoken range commands they play. Both are managed from the web app, and both
come in two kinds — **shipped** with the firmware, and **uploaded** afterwards.

The difference matters because shipped content cannot be changed or deleted
from the web app. It is part of the firmware image, so a new firmware brings a
new set; nothing done at the range can remove it. Uploaded content is yours to
add, replace and delete.

## Programs

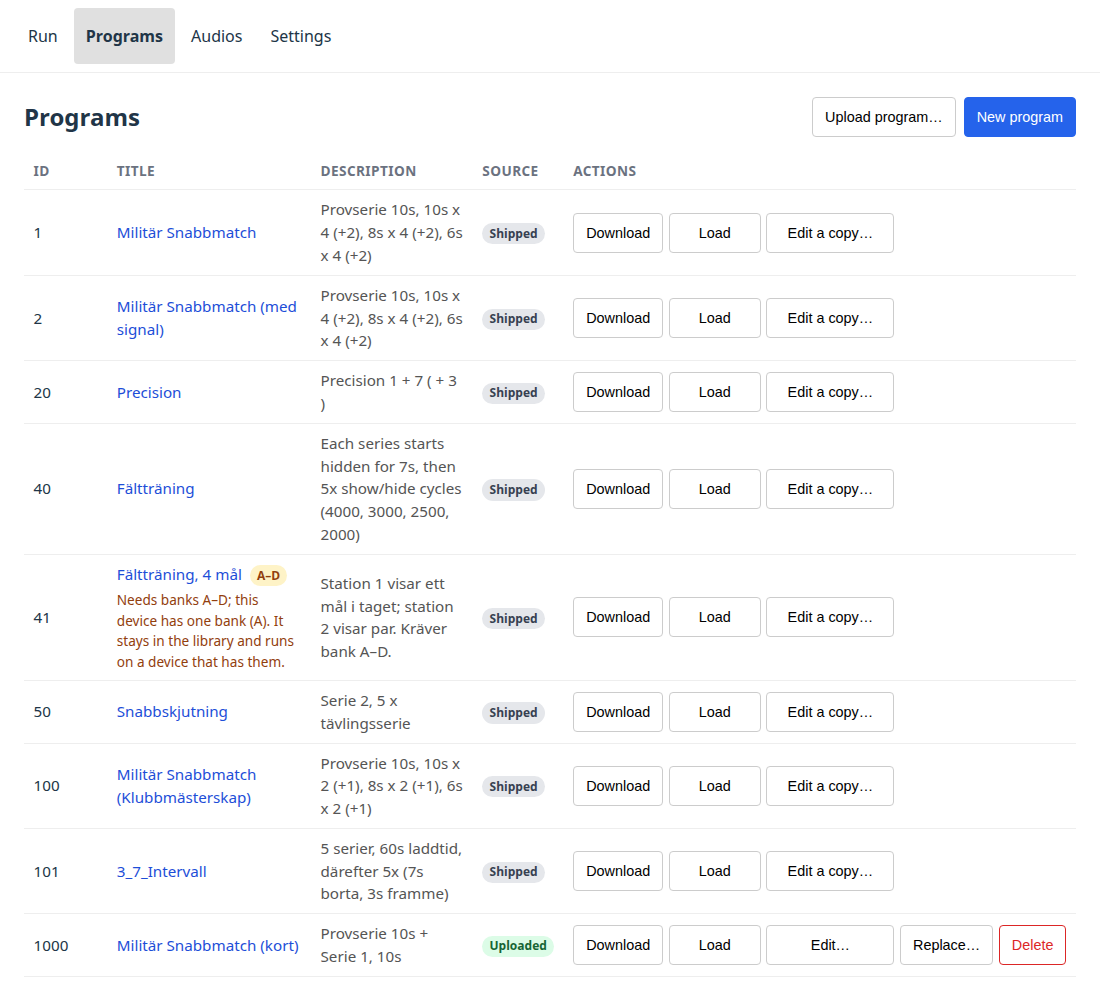
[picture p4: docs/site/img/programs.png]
The Programs page


Each row is one program. **Source** says shipped or uploaded, and the actions
follow from it: an uploaded program can be edited, replaced and deleted, a
shipped one only downloaded or copied.

- **Load** makes it the program the Run page will run. Only one program is
  loaded at a time, and the row says which.
- **Download** saves the program as a `.json` file — the way to get a copy of
  a shipped program to start from.
- **Edit a copy…** on a shipped program opens the editor on a copy, which
  uploads as a new program and leaves the original alone. On an uploaded
  program, **Edit…** changes it in place.
- **Replace…** overwrites an uploaded program from a file.
- **Delete** removes an uploaded program. A shipped one refuses with an
  explanation rather than disappearing from the list.

### Ids

Ids below 1000 are shipped; uploads are numbered from 1000 up. The device
picks the id, not the file — the number inside an uploaded document is
ignored — and it hands back the lowest free one, so deleting 1001 and
uploading again gives 1001 rather than stepping past it.

### Editing

**New program** and the **Edit** actions open the same editor: series and
events as a form, the JSON the device will actually receive on a second tab,
and a read-only timeline preview underneath both. Events carry a duration,
whether they show or hide the targets, and any audio clips to play on entry.

The editor checks the document against what the device will accept before it
sends anything, and says what would be changed or refused rather than letting
the device answer with an error after the fact.

## Audio

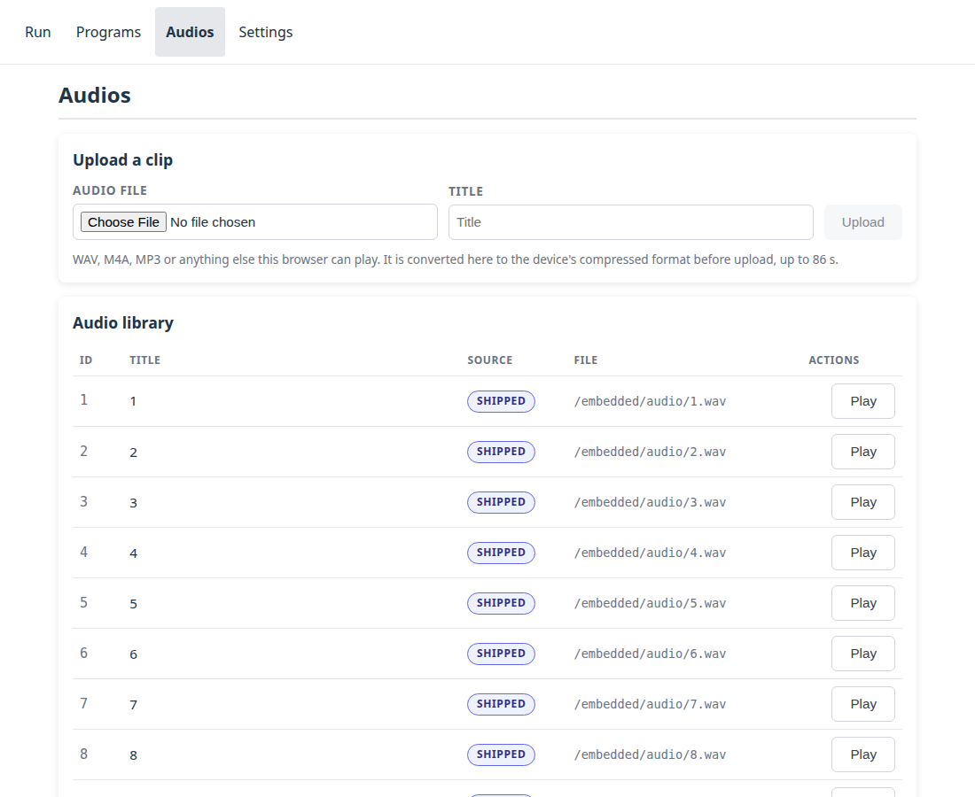
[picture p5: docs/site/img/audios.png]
The Audios page


You can upload a recording straight from your phone: **M4A, MP3, WAV**, or
anything else your browser can play. The browser converts it to the device's
compressed format before it is sent, which takes a moment, caps a clip at just
under a minute and a half, and leaves room for about four times as many clips as
uncompressed WAV would. Anything the device cannot play is refused at upload
rather than failing silently mid-exercise.

The clips that come *with* the device are compressed, which is why they take
about a quarter of the room they used to and why there is more space for yours
than there was. It makes no audible difference at the range — the same file is
what the speaker gets either way — and the originals live in the project's
source, so nothing is lost.

**Play** sends the clip to the device's own amplifier — not to the browser —
so it is a check on the wiring and the speaker, not on the file.

### What cannot be deleted, and why

A spoken command that silently fails in the middle of an exercise is a
range-safety problem, so the device refuses a delete that could cause one. In
the order it checks:

| Reason | Lifts when |
|---|---|
| The clip is shipped with the firmware | never |
| The loaded program plays it | another program is loaded, or the current one is unloaded |
| A run is in progress | the run is paused or finished |
| The device is playing that clip right now | the clip finishes |

Note the second one: pausing is not enough. **Pause** keeps the run's exact
position, so a clip deleted between two halves of a paused run would be
missing when it resumes. Unload the program, or load a different one.

## Getting a program into the shipped set

Uploaded programs live on one device. A program that should be on every
device — and survive a reflash — belongs in the repository, where it ships
with the next firmware.

The route is: **Download** the program from the Programs page, then open a
pull request adding it under `resources/programs/files/` with a filename of
`<id>.json` — an id below 1000, not already taken. The same applies to audio
clips under `resources/audios/`.

The [program editor](https://malmo-skyttegille-pistolsektionen.github.io/revolve_now/editor/) does both halves for you — see
[Writing your own program](writing-a-program.md).

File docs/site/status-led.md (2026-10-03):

# Status LED

The status LED needs a page of its own, because it is the only thing the
device tells you when nobody has a browser open — and at the range that is the
normal case.

There are **two sequences**, not one, and which you are watching is the first
thing to work out: a device that knows a network, and a device that does not.

## A device that knows a network

The ordinary startup, every time the board is powered on at the range:

| LED | Means | What to do |
|---|---|---|
| **Blinking red** | Trying to join the stored network | Wait — it blinks once per join attempt, about every 2.4 s |
| **Yellow** | On the network, not serving yet | Normally invisible (~24 ms). If it *stays* yellow, WiFi is fine and the HTTP server is the fault |
| **Green** | Serving | Normal running state — [go and find it](connecting.md#finding-the-device) |

Blinking red for a few seconds on every boot is expected; joining a network is
not instant. It is only a problem if it does not end.

## A device that does not

A board that has never been configured, or that has been moved somewhere its
stored network does not exist, runs out of attempts and offers a network of its
own instead:

| LED | Means | What to do |
|---|---|---|
| **Blinking red** | Trying, and failing, to join | Wait for it to give up — it will |
| **Blue** | Setup portal on its own access point | [Join it and configure a network](connecting.md#the-setup-portal) |

After the portal saves a network, the device restarts and runs the first
sequence instead: blinking red, then green.

**Solid red** belongs to neither: it means the device gave up *and* did not
raise the portal. That is a fault rather than a state to act on — see
[Troubleshooting](troubleshooting.md).

## White — you are holding the button

**White** is not a state the device gets into on its own. It appears three
seconds into a hold of the **BOOT** button and means the device is counting
towards a [factory reset](connecting.md#moving-the-device-to-a-different-network).

Let go and it goes back to whatever colour it was showing. Keep holding to ten
seconds and it restarts, having forgotten every network it knows.

If you see white and did not mean it, let go — nothing has happened yet.

If the LED goes white **on its own**, without anybody touching the button, the
button is stuck or shorted. The device notices — it refuses to act on a button
it has never seen released, so it will not reset itself — but the button will
not work until the fault is fixed. The serial log says so in as many words.

## Three things worth saying, because none is guessable

- **Blinking versus solid red is the important distinction.** Before
  [#122](https://github.com/Malmo-Skyttegille-Pistolsektionen/revolve_now/issues/122)
  both were solid, so "still coming up" and "never joined" looked identical —
  which is exactly the question you have at the range.
- **Yellow is a fault indicator, not a stage.** It exists to be seen only when
  something is wrong.
- **White is the only colour that answers to you rather than reporting on the
  device.** Every other colour is something to read; white is feedback on
  something you are doing to it right now.

The LED is deliberately dim: the device sits on a range in the dark and a
bright indicator is a distraction downrange. Photographs for these docs should
be taken in low light or it will not read as the colours above.

<!-- TODO: low-light photographs of each LED state, per the note above -->

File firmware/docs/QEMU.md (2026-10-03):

# Running the firmware in QEMU

The firmware boots unmodified in Espressif's QEMU fork, serves the real REST
API, the real SSE stream and the real webapp out of the real LittleFS image,
and answers on `http://localhost:8080`. That makes a browser session or an E2E
suite possible without a board on the desk, against the same code that ships —
not a mock.

```sh
. <esp-idf>/export.sh
firmware/scripts/run-qemu.sh
# then: http://localhost:8080   (Ctrl-A X quits QEMU)
```

The script installs `qemu-xtensa` on first use
(`python "$IDF_PATH/tools/idf_tools.py" install qemu-xtensa`), builds the QEMU
profile into `build-qemu/`, merges the flash image and boots it. `--build-only`
stops after the build; `--headless` boots with no terminal attached;
`--port N` changes the host port.

Boot to serving takes about two seconds of guest time.

## How it differs from the board

QEMU emulates no WiFi radio, so the network comes up over the OpenCores
Ethernet MAC the emulator maps onto the EMAC register window. That is the whole
of `CONFIG_RT_NET_OPENETH`: `main/net/eth_mgr.cpp` is compiled instead of
`main/net/wifi_mgr.cpp`, both implementing `main/net/net_mgr.h`. With the WiFi
translation unit out of the build, the setup portal and the NVS credential
store are not linked in at all — there is nothing to provision, because SLIRP
hands the guest 10.0.2.15 over DHCP.

The rest of the profile is `sdkconfig.defaults.qemu` layered on
`sdkconfig.defaults`: audio and the RGB LED off, PSRAM addressed as quad (see
below), everything else — 16 MB flash, the partition table, the socket
budget — exactly as the board has it.

## What works

| | |
|---|---|
| REST `/api/v2/*` | All of it, including the control lock and `diagnostics/info` |
| SSE `/sse/v2` | `stateUpdate` and `heartbeat`, real timing |
| The webapp | Served from LittleFS at `http://localhost:8080` when `webapp/dist` exists at build time, `.gz` assets included |
| LittleFS | Mounts the flashed image: 7 shipped programs, 77 audio entries, uploads |
| Executor timing | Tracks host wall-clock — `tickerMs` advances once a second and series boundaries land where the program says |
| Watchdogs | Disabled by the runner (`wdt_disable`); nothing feeds them under emulation |

## What does not work

- **Audio is silent.** There is no I2S peripheral to emulate, so
  `RT_AUDIO_ENABLED` is off and `main/io/audio.cpp` takes its no-op path.
  Programs still run, and the API still reports the audio catalogue.
- **The RGB LED does nothing.** No RMT peripheral; `RT_RGB_LED_ENABLED` is off
  and `main/io/rgb_led.cpp` takes its no-op path.
- **GPIO writes are discarded.** The target pin is driven exactly as on the
  board, but nothing in the emulator observes it and a pad readback does not
  reflect a write. Where the API says the banks are comes from the executor,
  not from the pin — `diagnostics/info` shows `banks[].padLevel: 0` throughout.
- **mDNS is not reachable from the host.** The responder runs and answers
  inside the guest, but SLIRP does not carry multicast to the host — use
  `localhost:8080`, never `revolve-now.local`.
- **CORS by device IP does not match.** The allowlist knows
  `revolve-now.local` and the guest's own 10.0.2.15; a browser on
  `http://localhost:8080` sends that origin instead. Same-origin requests need
  no CORS headers, so the bundled webapp is unaffected; a Vite dev server
  against the emulator needs `CONFIG_RT_DEV_ORIGIN`.
- **`GET /api/v2/version` reports `0.0.0`.** The app version is a raw
  `git describe`, which that endpoint's strict parse rejects. Not a QEMU
  artefact — the board does the same until versioning lands.
  `diagnostics/info` reports the describe string verbatim.

Noise that is expected on every boot and safe to ignore:

```
E esp_eth: esp_eth_ioctl(533): add mac address to filter not supported
E esp_netif_lwip: Failed to add multicast filter for IPv4
W opencores.emac: emac_opencores_isr_handler: RX frame dropped (0x14)
W rtcinit: o_code calibration fail
```

The OpenCores MAC has no multicast filter, so lwIP's IGMP setup fails; a frame
or two is dropped while the DMA rings fill; the RTC calibration has nothing to
calibrate. Nothing downstream depends on any of it.

## Two things the emulator gets wrong, and what the runner does about them

**PSRAM is addressed as quad, not octal.** The board is an N16R8 and
`sdkconfig.defaults` says `CONFIG_SPIRAM_MODE_OCT`. Under qemu-xtensa 9.2.2 the
octal model segfaults the emulator inside `psram_transfer()`
(`hw/misc/ssi_psram.c`) during the driver's init transfer — deterministically,
right after `boot: Loaded app from partition` and with no guest output at all,
so it reads as a silent hang. `sdkconfig.defaults.qemu` therefore selects
`CONFIG_SPIRAM_MODE_QUAD` at 40 MHz. The pool is the same 8 MB and nothing
above the driver can tell the difference. Revisit when the emulator's octal
model is fixed.

**PSRAM size must be passed explicitly.** `idf.py qemu` hardcodes `-m 32M`. At
that size the guest's PSRAM claims the entire external-memory virtual address
range:

```
W esp_psram: Virtual address not enough for PSRAM, map as much as we can. 31MB is mapped
E mmap: esp_mmu_map(479): no such vaddr range
E partition: load_partitions returned 0x105
ESP_ERROR_CHECK failed: esp_err_t 0x105 (ESP_ERR_NOT_FOUND)
```

Every flash mmap after PSRAM init fails and the app aborts in
`nvs_flash_init()`. The runner passes `-m 8M`; override with `QEMU_PSRAM_MB`
for a different module.

Because neither of those can be expressed through `idf.py qemu`, the runner
builds with `idf.py` but invokes `qemu-system-xtensa` directly, merging the
flash image with the same `esptool merge-bin` call `idf.py qemu` would have
used. It also omits the eFuse drive `idf.py qemu` always attaches — that image
describes a chip revision v0.3 part, and on v0.3 the PSRAM driver runs MSPI
timing tuning, another path the emulator faults in. Without the drive the eFuse
reads back as v0.0 and the tuning is skipped.

## Running it in CI

`run-qemu.sh --headless` is the CI shape: no TTY needed, serial goes to stdout.

The `firmware boot smoke` job in `.github/workflows/firmware-build.yml` is the
worked example: build, boot, poll, assert `/api/v2/version`, `/api/v2/programs`,
one SSE `stateUpdate` and the API-only `GET /` 404.

```sh
firmware/scripts/run-qemu.sh --build-only
firmware/scripts/run-qemu.sh --no-build --headless > qemu.log 2>&1 &
# poll http://localhost:8080/api/v2/version until it answers, then assert
```

`--no-build` is what keeps the boot half honest: without it the backgrounded
run re-runs a no-op `idf.py build` first, and a boot timeout would be timing
the build. No `idf_tools.py install qemu-xtensa` either - `espressif/idf:v6.0.2`
already ships qemu-xtensa 9.2.2 on `PATH`, so there is nothing to cache; the
runner's install-on-first-use branch is for a bare IDF checkout.

The flag matters: interactive runs get `-serial mon:stdio`, and QEMU quits the
instant that stdin reports EOF — which is exactly what a CI runner or a
backgrounded shell hands it. Headless runs get `-serial file:/dev/stdout` and
`-monitor none` instead, and never read stdin at all.

## Not for real hardware

`CONFIG_ETH_USE_OPENETH` is documented upstream as "for use with QEMU… not
supported when running on a real chip". A build with `CONFIG_RT_NET_OPENETH=y`
will not reach a network on the board; it is a simulator profile and nothing
else. The board build is the default and is untouched by any of this.

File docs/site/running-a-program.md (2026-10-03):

# Running a program

## Loading

Pick a program from the dropdown on the Run page. Choosing one **loads** it —
it does not start it. The device confirms what it has loaded before the page
lets you do anything with it; a program picked but not yet confirmed leaves
Start disabled for a moment.

A program is a series of **series** — a match's separate strings of fire, for
example — each with its own targets and events. If the program has more than
one, a second dropdown picks which series to run first; skip ahead to a later
one at any point (see [Skipping](#optional-series-and-skipping) below).

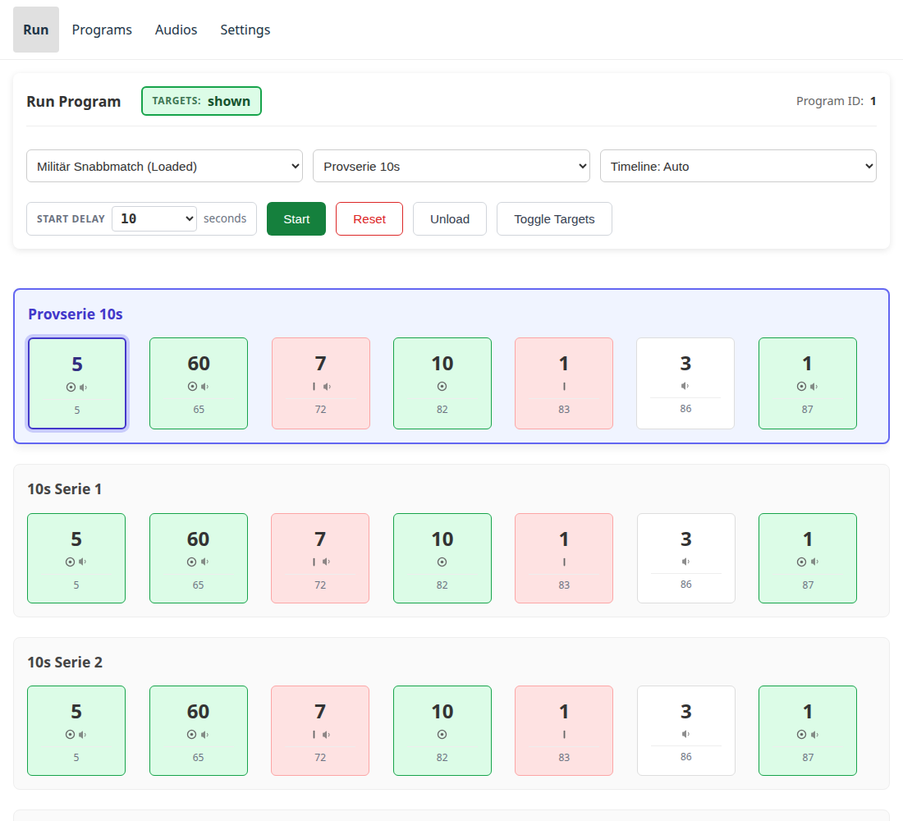
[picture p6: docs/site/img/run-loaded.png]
The Run page with a program loaded


## Starting

**Start delay** sets how many seconds count down before the program actually
starts — **No delay** starts it at once. It is saved in the browser you set it
in, so another phone or tablet at the same range keeps its own value.

With a delay set, Start opens a countdown with its own **Start Now** (skip the
rest of the wait) and **Cancel** buttons. The countdown is cancelled
automatically if the device's loaded program changes underneath it — another
tab or device on the range changed something — and a message explains why.

Once running:

- **Pause** stops the run and keeps its exact position, down to the
  millisecond — a resume with no delay set picks up from there, not from the
  start of the series.
- **Reset** rewinds to the start of the *current* series (the series stays
  selected; only its position resets). Only available while paused.
- **Unload** clears the loaded program entirely. Offered even mid-run: the
  device refuses it while a program is running and explains why, so Pause is
  the way out of that refusal.
- **Toggle Targets** flips the targets show/hide directly, independent of any
  program — useful for checking the wiring works at all.

On a device with more than one [target bank](hardware.md#target-banks), the
`TARGETS` badge at the top of the page becomes a **strip**: one cell per bank,
lettered A onward, green for shown and red for hidden, with the bank's name
under the letter on a screen wide enough for it. So a range exposed one lane at
a time is one glance to read, and a bank that did not move is visible rather
than averaged away.

The controls follow it. Instead of one **Toggle Targets** button there is a
**Targets** group: tapping a lettered cell flips **that bank alone**, and
**Show all** / **Hide all** move every bank together. A one-bank device — which
is most of them — keeps the single badge and the single button, unchanged.

Until the device has said where the targets are, the badge reads `-` rather
than guessing.

## The timeline

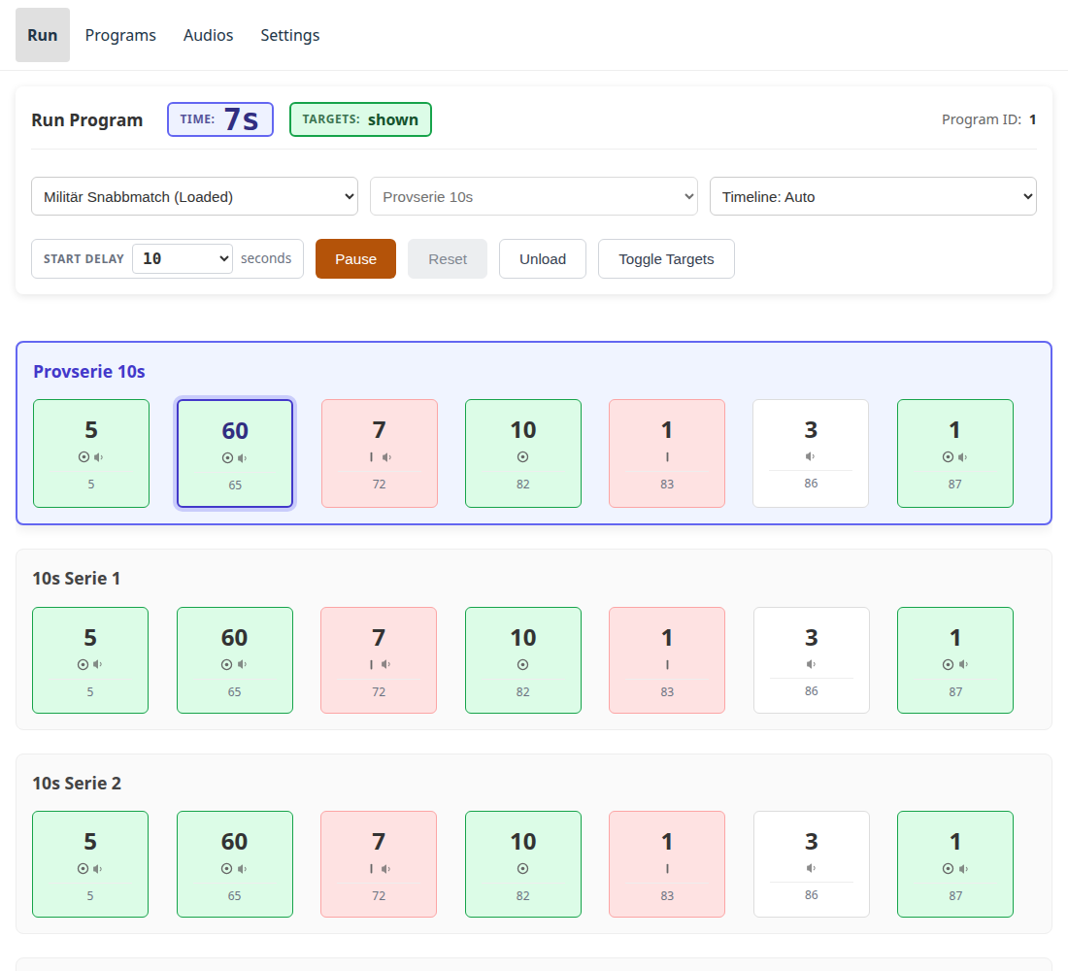
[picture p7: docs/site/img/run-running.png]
A run in progress


The Run page shows every series and event in the loaded program, and tracks
the run live as it plays:

- Each event shows its duration, whether it shows or hides the targets, and
  whether it plays a range command over the amplifier.
- Point at (or tap) an event to see its full detail — including which audio
  clips it plays, named rather than by number.
- The running series scrolls into view automatically as the run reaches it.

Three display modes are available from the dropdown beside the program
picker: **Auto** picks the layout that suits the loaded program, **Event-based**
draws events as a fixed-width sequence, and **Time-scaled** draws them
proportional to their actual duration, with a moving cursor showing exactly
where the run is right now.

## Optional series and skipping

Some series are marked **optional** — a warm-up string, for example — and
carry a badge on the timeline to say so. While the run is sitting at an
optional series (not while it is playing), a **Skip** button on that series
moves straight to the next one without running it.

The series dropdown reaches every series directly, at any time the program is
not running, in case the run needs to jump further than one step — but
skipping mid-run is not offered: **Pause** is how a series in progress gets
cut short.

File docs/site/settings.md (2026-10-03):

# Settings

The Settings tab holds two different kinds of thing, and it is worth knowing
which is which before changing anything:

- **Browser settings** live in the browser you are using. Another phone or
  tablet at the same range keeps its own, and clearing site data resets them.
- **Device settings and readouts** come from the board itself, and are the
  same for everyone looking at it.

| Section | Kind | What it is |
|---|---|---|
| Server Base URL | browser | Which device this browser talks to |
| Address | device | The address the device says it is reachable on |
| Control lock | device | Whether control is open to everyone or needs a login |
| Startup Issues | device | What the device could not read when it booted |
| Storage | device | How much room the flash partitions have |
| WiFi | device | Which network it is on, and how good the link is |
| About | device | What firmware and web app this is, and exactly which build |

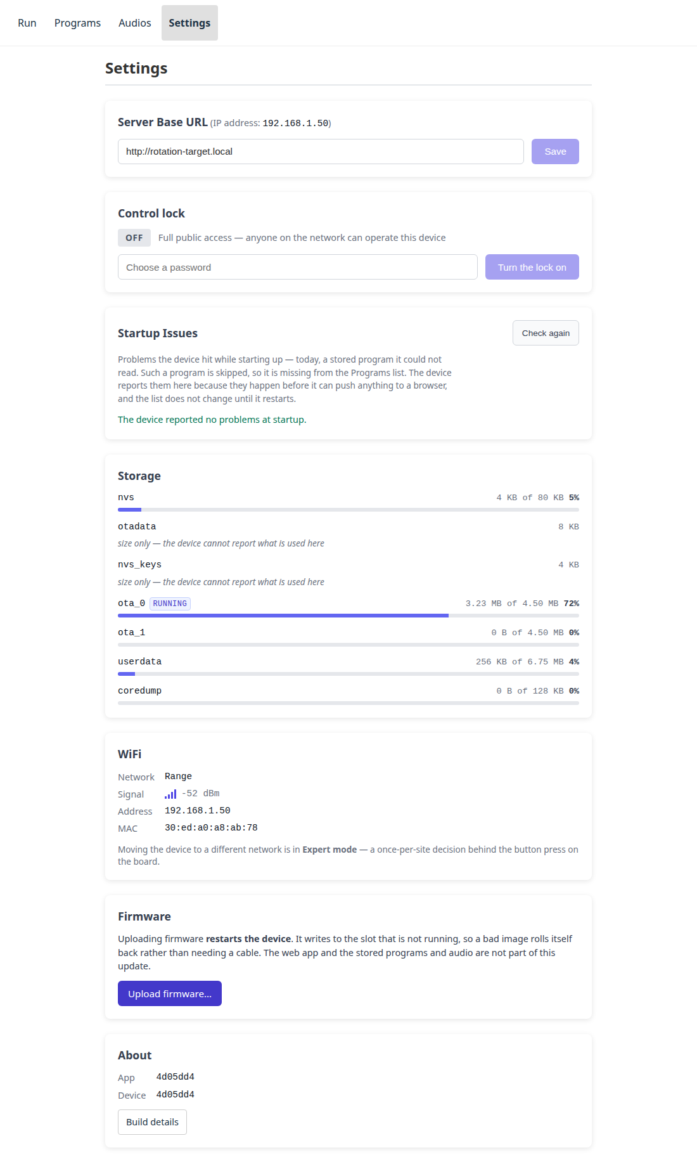
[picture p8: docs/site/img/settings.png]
The Settings page


Nothing on this page can stop the device working. The settings that can —
which network it joins, which pins it drives, and the crash dump download —
are on [Expert mode](expert-mode.md), behind a button press on the board
itself.

**One line can appear at the top:** *Configuration saved but not applied;
restart from Expert mode.* It means somebody changed a setting on that page and
the device is still running what it started with. The change is not lost and
nothing is broken — it needs
[**Restart to apply**](expert-mode.md#restart-to-apply), which is on that page
whether or not the five-minute window is still open. It is here so that the
next person to pick the device up finds out, rather than being surprised by it
at the next power cycle.

**Target banks are configured there too.** How many lines this device drives,
what each is called and which pin it is on is Expert-mode work —
[the bank table](expert-mode.md#the-target-banks) — because a wrong pin is one
of the settings whose way back is a USB cable. What you see on the Run page —
the lettered strip and the per-bank buttons — follows from it, and needs
nothing set here.

## Server Base URL

Normally there is nothing to do here — the app talks to whatever served it.
It matters when the app is being run from somewhere other than the device
(during development, or from a copy on a laptop) and needs pointing at a board.

## Address

What the device reports as its own address. If it says the device has no
address, it is serving its own access point instead of being on a network —
see [the setup portal](connecting.md#the-setup-portal).

## Control lock

Two states:

- **Full public access** — anyone who can reach the page can control the
  device. This is the default, and it is usually what a range wants: no
  password to pass around while people are shooting.
- **View only** — the page still shows what is happening, but starting,
  stopping, uploading and deleting all require a login.

Turning it on asks for a password to set. From then on this browser holds a
token; **Login** on another browser asks for that password again.

The password protects against the accidental rather than the determined: the
device is on the range's own network, and the traffic is plain HTTP.

## Startup Issues

What the device could not read when it booted: a program file that does not
parse, a clip whose header is not a WAV it can play. The list is bounded and
drops the oldest, so a device with many bad files shows the most recent ones.

An empty list is the normal state and says the boot scan read everything.

## Storage

Partition sizes. Note the note: **size only — the device cannot report what is
used here** for some partitions, so a figure being absent is not a fault.

The one to look at is **`userdata`**. It holds what has been uploaded to the
device — programs and audio clips — and nothing else. Everything that ships
*with* the device is inside the firmware itself, so the shipped set growing can
no longer eat the room for yours, and updating the device cannot touch what you
put on it.

`ota_0` and `ota_1` are the two copies of the firmware. One is running and the
other is where an update is written, which is what lets a bad update be undone.
Seeing one of them nearly empty is normal on a device that has never been
updated.

## WiFi

Which network the device joined, how strong the signal is, the address it is
reachable at, and the MAC address a router lists it under. All of it is a
readout — nothing here changes anything.

**Which network matters, not just that there is one.** A device remembers the
network it was set up on *and* the one its firmware was built for, and joins
whichever it can see. A board that has been to two places may be on either, and
this is where you find out which.

**Signal** is shown as bars and as a number in dBm. The number is negative and
closer to zero is stronger — around −50 is excellent, −70 is workable, and
below about −80 is where a device starts dropping off the network. It is the
figure to watch while moving a board around looking for somewhere to mount it.

If it says **no network has been saved**, nobody has set this device up here.
It is running on whatever network its firmware was built for, which cannot be
read back or changed without rebuilding it — so if it is working, it is working
by luck of being in the right building.

To *change* the network, see [Expert mode](expert-mode.md#wifi). It is a
once-per-site decision behind the button press on the board, which is why it is
not on this page.

## About

**App** is the version of the page you are looking at. **Device** is the
firmware's. One version number covers firmware, web app and shipped content,
and the web app is part of the firmware image itself — so a page served *by*
the device always matches it, however the device was updated.

That includes an update sent over the network, which used to be the awkward
case: it replaced the firmware and left the web app behind, so a device could
serve a page older than the firmware running it until somebody flashed it over
USB. That cannot happen any more. The shipped programs and audio are still
stored separately and are still not updated over the network.

So a mismatch now means one thing: **this page did not come from that device.**
A development build, or a copy served from a laptop, pointed at a board built
from a different commit.

A hard reload will not help. The browser is showing the version it was given;
the two really are different.

**Modified build** beside the device version means the firmware was built from
a working copy with uncommitted changes. On a board flashed from a release that
should not appear; on a board somebody has been developing against, it is
normal.

### Build details

**Build details** opens a table naming exactly which build this is: the commit,
when it was built, which branch it came from, the ESP-IDF version, and
fingerprints of the web app and audio it was built with.

None of it is worth reading day to day. It exists for one situation: **a board
that has come back from a range day behaving oddly.** "Which firmware is this"
is answerable from the version alone; "which commit, built where, with which
audio set" is not, and those are the questions that get a fault diagnosed.

**Copy** puts the whole block on the clipboard, ready to paste into a bug
report — which is the only thing it is for. If your browser refuses (some do on
a plain `http://` address, which is what the device serves), the text appears
below instead so you can select it by hand.

## Troubleshooting

The crash dump download has moved to [Expert mode](expert-mode.md#troubleshooting).
It is behind the device's BOOT button because a crash dump can contain the WiFi
password, and everything behind that button is now on one page rather than
appearing and disappearing on this one.

[Sending a fault report](troubleshooting.md#sending-a-fault-report) has the
steps and what it means for who you send it to.

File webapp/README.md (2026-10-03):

# Revolve Now web app

This project is a frontend application for controlling rotating targets for Malmö Skyttegille shooting club. The system communicates with an ESP32 backend via REST API and Server-Sent Events (SSE).

## Tech Stack

- **Language:** TypeScript
- **Framework:** React 19
- **Routing:** TanStack Router
- **State/Data:** TanStack Query
- **Build Tool:** Vite
- **Package Manager:** npm
- **Styling:** CSS Modules (CLSX)
- **Linting/Formatting:** ESLint, Prettier

## Features

The web app has the following main features:

1.  **Run Tab:**
    - Load programs (shooting series).
    - Start/stop series.
    - Show timeline and stopwatch for series.
    - Manual target control (Show/Hide).
    - Real-time updates from hardware via SSE.

2.  **Audio Tab:**
    - Upload audio files to hardware.
    - Play audio (for testing).
    - Manage audio library.

3.  **Programs Tab:**
    - List the programs on the device, shipped and uploaded.
    - Load a program, upload one from a file, replace one, delete one.
    - Inspect a program's timeline and download its JSON.
    - Author a program in the editor: series and events, durations, target
      commands and audio clips, with a JSON view and a timeline preview.

4.  **Settings Tab:**
    - Configure backend IP address.
    - The control lock.

5.  **Program editor, off the device (GitHub Pages):** the same `ProgramEditor`
    component as the Programs tab, in a "no device" mode — open a program from
    this repo, another repo, or a local file (or start empty), edit it, then
    download it or send it back as a pull request. See
    [Standalone program editor](#standalone-program-editor-github-pages)
    below.

## Development

### Start dev server

```bash
npm run dev
```

This starts the Vite server at `http://localhost:8080`.
A built-in **Mock Server** simulates the hardware API and SSE streams, so you can develop without physical hardware. It lives in `test/mock-server/`;
`vite-plugins/mock-server-v2.ts` only mounts it on the dev server. Interim —
E2E is moving to the real firmware under QEMU.

### Tests

```bash
npm run test        # once, as CI runs it
npm run test:watch
```

Vitest, with happy-dom for the suites that touch the DOM (opted into per file
with `@vitest-environment happy-dom`). Suites that need an API construct the
mock server with a **fake clock**, so a 28-second series is simulated in
microseconds instead of 28 seconds of wall clock.

### Build for production

```bash
npm run build
```

This generates an optimized build in the `dist/` folder.

### Version

The bundle's version is the release tag, resolved at build time by
`vite.config.ts` from the same `git describe` the firmware's CMake runs and
injected as `__APP_VERSION__` (read it through `src/appVersion.ts`). The webapp
ships inside the firmware image, so the two report identical strings; the
Settings page shows both, and flags a disagreement.

`package.json`'s `"version": "0.0.0"` is a **placeholder**. npm wants the field;
nothing reads it and nothing bumps it. A release is a tag — see
[`docs/RELEASING.md`](../docs/RELEASING.md) and D-29 in the decision log.

### Code style

The project uses strict ESLint and Prettier.

```bash
npm run lint
npm run format
```

### Size budget

CI fails the build if the gzipped total of `dist/**/*.{js,css}` exceeds the
ceiling in `webapp/size-budget` (the same check as
`.github/workflows/webapp-build.yml`). To regenerate it after a deliberate
size change (current total + 5%):

```bash
npm run build
total=0
while IFS= read -r -d '' f; do
  total=$((total + $(gzip -nc "$f" | wc -c)))
done < <(find dist -type f \( -name '*.js' -o -name '*.css' \) -print0)
echo "$total * 1.05" | bc | cut -d. -f1 > size-budget
```

This measures `dist/`, produced by `npm run build` (`vite.config.ts`) only.
The standalone program editor below is a **separate build**
(`vite.editor.config.ts`, output `dist-editor/`) precisely so that adding to
it never grows this number — see the comment on `ProgramEditor`'s
`renderExport` prop for how the device build avoids even importing that code.

### Standalone program editor (GitHub Pages)

```bash
npm run dev:pages-editor          # http://localhost:8080, no mock API mounted
npm run build:pages-editor        # -> dist-editor/, base /revolve_now/editor/
```

`editor.html` / `src/editor-main.tsx` build the same `ProgramEditor` component
the Programs tab uses, in a mode with no device: it opens a program from a
GitHub repo's `resources/programs/files/` (via the contents API, no auth
needed for a public repo), from a local file, or empty; downloads the result;
and can hand it back as a pull request through a prefilled
`github.com/<owner>/<repo>/new/main` URL — no OAuth, no token, nothing to
leak. See [`src/lib/pr-url.ts`](src/lib/pr-url.ts) and
[`src/lib/github-contents.ts`](src/lib/github-contents.ts).

`.github/workflows/pages.yml` builds this alongside the MkDocs docs site
(`#134`) and deploys both as one GitHub Pages artifact, the editor nested
under `/editor/` — GitHub Pages has one deployment target per repo, so two
workflows both calling `deploy-pages` would race each other for it.

## End-to-end tests

The E2E suite (`e2e/`, Playwright) runs against the **real firmware** booted in
QEMU — not the mock server, and not a dev-server proxy. The webapp is built,
its `dist` is baked into the LittleFS image through `RT_WEBAPP_DIR`, that image
is booted, and the browser is pointed at the forwarded guest port. The bundle
under test is the artefact the board actually serves, so the webapp cannot
drift away from the backend without a red build.

```bash
. <esp-idf>/export.sh               # QEMU needs the ESP-IDF toolchain
npm ci
npx playwright install chromium     # `.npmrc` sets ignore-scripts; not automatic
npm run e2e:local                   # build -> boot QEMU -> test -> tear down
```

`e2e/run-local.sh` takes `--skip-build` (reuse the existing `dist` and
`build-qemu`) and `--port N`, and passes anything after `--` to
`playwright test`. It always kills QEMU on the way out, and prints the tail of
the guest serial log when something fails.

`npm run e2e` runs the tests alone, against whatever is already serving on
`RT_E2E_BASE_URL` (default `http://localhost:8080`) — a QEMU instance you
started yourself, or a real board.

Notes for writing tests:

- There is **one device** and its state persists across tests, so the config
  pins `workers: 1` and every spec calls `resetDevice()` in `beforeEach`.
- Deep links are fine to navigate to: the firmware answers a non-API `GET` miss
  with `index.html`, so `/run` reloads as the page it is.
- `backend_issue` is not covered — it needs audio hardware, and QEMU emulates
  no I2S.

CI runs the same thing in `.github/workflows/webapp-e2e.yml`.

## API types

`src/api/generated.d.ts` is generated from the canonical REST contract
(`../contracts/openapi.yaml`) by `openapi-typescript`:

```bash
npm run generate:api
```

The output is committed, and CI re-runs the generator and fails the build on
`git diff` — so a merged contract change that the webapp hasn't caught up
with is a red build, not a silent runtime mismatch. `src/api/types.ts`
re-exports the shapes it actually uses from `components['schemas'][...]` in
the generated file; SSE payload types (`contracts/asyncapi.yaml` is not fed
to the generator) stay hand-written there.

The app does not ship a JSON Schema. `src/lib/program-document.ts` validates
program documents against what the firmware's `parse_program` actually does
(D-18); `test/program-document-schema.test.ts` cross-checks that against
`../contracts/program.schema.json` with ajv, which is why ajv is still a
devDependency.

## UI/UX

Primary audience is tablet and mobile, which requires larger, touch-friendly buttons and controls.

## Project Structure

- `src/`: Source code (React)
  - `routes/`: Application routes (TanStack Router)
  - `components/`: Reusable components
  - `hooks/`: Custom hooks (e.g. useSSE)
  - `api/`: API clients and types
  - `lib/`: Pure logic shared with the mock server (e.g. run-position, which
    mirrors `firmware/lib/rt_logic/run_position.h`)
- `vite-plugins/`: Dev-server plugins (the mock server adapter)
- `test/`: Unit tests, fixtures and the mock server implementation

## Security

The project is configured to minimize supply-chain attack risk:

- Dependencies are locked via `package-lock.json` (`npm ci` in CI).
- Install scripts are disabled via `.npmrc` (`ignore-scripts=true`); no
  package's `postinstall`/`preinstall` runs on `npm install` or `npm ci`.
- Yarn's `npmMinimalAgeGate` (a per-install minimum package age) has no npm
  equivalent; the managed path is instead covered by the org's shared
  Renovate config, `minimumReleaseAge` (3 days for minor/patch updates, 7
  days for major).

## Contact

Project maintained by MSG.

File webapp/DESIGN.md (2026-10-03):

---
name: Revolve Now
description: Range-side control for a rotating pistol target — equipment that happens to have a screen.
colors:
  # The light theme, and the names of the CSS custom properties: `ink` is
  # `--rt-ink` in src/theme.css. Dark values are in the Colors section below.
  page: '#ffffff'
  surface: '#ffffff'
  surface-sunken: '#fafafa'
  surface-muted: '#f3f4f6'
  fill: '#e5e7eb'
  fill-hover: '#d1d5db'
  border: '#e5e7eb'
  border-strong: '#d1d5db'
  border-hover: '#9ca3af'
  ink: '#111827'
  text: '#213547'
  text-strong: '#374151'
  text-subtle: '#4b5563'
  text-muted: '#6b7280'
  on-fill: '#ffffff'
  focus: '#2563eb'
  action: '#2563eb'
  action-deep: '#1d4ed8'
  action-text: '#1d4ed8'
  action-tint: '#eff6ff'
  action-tint-strong: '#dbeafe'
  accent: '#6366f1'
  accent-deep: '#4338ca'
  accent-ink: '#312e81'
  accent-tint: '#eef2ff'
  accent-border: '#c7d2fe'
  accent-fill: '#4338ca'
  accent-fill-deep: '#3730a3'
  shown: '#16a34a'
  shown-ink: '#15803d'
  shown-text: '#14532d'
  shown-tint: '#dcfce7'
  shown-tint-soft: '#f0fdf4'
  go: '#15803d'
  go-deep: '#166534'
  stop: '#dc2626'
  stop-deep: '#b91c1c'
  stop-ink: '#dc2626'
  stop-ink-deep: '#b91c1c'
  stop-text: '#7f1d1d'
  stop-tint: '#fee2e2'
  stop-tint-soft: '#fef2f2'
  stop-border: '#fca5a5'
  warn: '#92400e'
  warn-ink: '#b45309'
  warn-fill: '#b45309'
  warn-fill-deep: '#92400e'
  warn-tint: '#fef3c7'
  warn-tint-strong: '#fde68a'
  warn-tint-soft: '#fffbeb'
  warn-border: '#fcd34d'
typography:
  # Eight steps, and every font-size in src/ is one of them. The ramp was
  # derived from what the app already shipped rather than imposed on it: the
  # sizes carrying real weight (0.85rem across 51 rules, 0.9rem across 37) were
  # simply never written down here, so the documented ramp and the CSS had
  # drifted apart in both directions.
  #
  # What was removed were the accidental near-duplicates - 0.7 beside 0.75,
  # 0.8 and 0.875 beside 0.85, and three components that each invented their
  # own `.title` size (1.05, 1.2, 1.25). Nothing moved by more than 0.15rem.
  display:
    fontFamily: "-apple-system, BlinkMacSystemFont, 'Segoe UI', Roboto, sans-serif"
    fontSize: 'clamp(4.5rem, 24vw, 7rem)'
    fontWeight: 700
    lineHeight: 1
    fontVariation: 'tabular-nums'
    usage: "The run screen's countdown, and nothing else."
  timer:
    fontFamily: 'Inter, system-ui, Avenir, Helvetica, Arial, sans-serif'
    fontSize: 'clamp(1.5rem, 5vw, 2rem)'
    fontWeight: 600
    lineHeight: 1.2
    usage: "The sticky timer that follows a run. Fluid on purpose - it has to stay readable on a phone held at arm's length and not dominate a laptop."
  headline:
    fontFamily: 'Inter, system-ui, Avenir, Helvetica, Arial, sans-serif'
    fontSize: '1.5rem'
    fontWeight: 600
    lineHeight: 1.3
    usage: "Page headings, and the timeline's duration readout."
  title:
    fontFamily: 'Inter, system-ui, Avenir, Helvetica, Arial, sans-serif'
    fontSize: '1.1rem'
    fontWeight: 600
    lineHeight: 1.4
    usage: 'Section and card titles. The one step three components had each guessed differently.'
  lead:
    fontFamily: 'Inter, system-ui, Avenir, Helvetica, Arial, sans-serif'
    fontSize: '1rem'
    fontWeight: 500
    lineHeight: 1.5
    usage: 'Controls that need to outweigh body text - a primary button, a card title in a dense list.'
  bodyLarge:
    fontFamily: 'Inter, system-ui, Avenir, Helvetica, Arial, sans-serif'
    fontSize: '0.95rem'
    fontWeight: 400
    lineHeight: 1.5
    usage: 'Text the operator reads off a device at the range: table cells, form inputs, read-only values.'
  body:
    fontFamily: 'Inter, system-ui, Avenir, Helvetica, Arial, sans-serif'
    fontSize: '0.9rem'
    fontWeight: 400
    lineHeight: 1.5
    usage: 'The default. Buttons, labels, most prose.'
  small:
    fontFamily: 'Inter, system-ui, Avenir, Helvetica, Arial, sans-serif'
    fontSize: '0.85rem'
    fontWeight: 400
    lineHeight: 1.5
    usage: 'Supporting text under a control - hints, metadata, error detail. The most-used size in the app.'
  label:
    fontFamily: 'Inter, system-ui, Avenir, Helvetica, Arial, sans-serif'
    fontSize: '0.75rem'
    fontWeight: 600
    lineHeight: 1
    letterSpacing: '0.05em'
    usage: 'Badges, group headings, tick labels. Anything set in caps.'
rounded:
  sm: '4px'
  md: '6px'
  lg: '8px'
  xl: '12px'
  pill: '999px'
spacing:
  xs: '0.25rem'
  sm: '0.5rem'
  md: '0.75rem'
  lg: '1rem'
  xl: '1.5rem'
  xxl: '2rem'
components:
  button-default:
    backgroundColor: '{colors.surface}'
    textColor: '{colors.text}'
    rounded: '{rounded.sm}'
    padding: '0.4rem 0.75rem'
    height: 'var(--rt-control-height)'
    typography: '{typography.body}'
  button-primary:
    backgroundColor: '{colors.action}'
    textColor: '{colors.on-fill}'
    rounded: '{rounded.sm}'
    padding: '0.4rem 0.75rem'
    height: 'var(--rt-control-height)'
  button-primary-hover:
    backgroundColor: '{colors.action-deep}'
    textColor: '{colors.on-fill}'
  button-destructive:
    backgroundColor: '{colors.surface}'
    textColor: '{colors.stop-ink}'
    rounded: '{rounded.sm}'
    padding: '0.4rem 0.75rem'
  button-destructive-hover:
    backgroundColor: '{colors.stop-tint}'
    textColor: '{colors.stop-ink}'
  button-go:
    backgroundColor: '{colors.go}'
    textColor: '{colors.on-fill}'
    rounded: '{rounded.lg}'
    padding: '0.75rem 1.5rem'
    height: '48px'
  button-stop:
    backgroundColor: '{colors.stop}'
    textColor: '{colors.on-fill}'
    rounded: '{rounded.lg}'
    padding: '0.75rem 1.5rem'
    height: '48px'
  input:
    backgroundColor: '{colors.surface}'
    textColor: '{colors.text}'
    rounded: '{rounded.sm}'
    padding: '0.35rem 0.5rem'
    typography: '{typography.body}'
  badge-shown:
    backgroundColor: '{colors.shown-tint}'
    textColor: '{colors.shown-text}'
    rounded: '{rounded.md}'
    padding: '0 0.75rem'
    height: '36px'
  badge-hidden:
    backgroundColor: '{colors.stop-tint}'
    textColor: '{colors.stop-text}'
    rounded: '{rounded.md}'
    padding: '0 0.75rem'
    height: '36px'
  badge-neutral:
    backgroundColor: '{colors.surface-muted}'
    textColor: '{colors.text-strong}'
    rounded: '{rounded.md}'
    padding: '0 0.75rem'
    height: '36px'
---

# Design System: Revolve Now

## Overview

**Creative North Star: "Equipment, not software"**

This is range equipment that happens to have a screen. It is read standing up,
outdoors, in daylight, by someone who is about to run a live firing exercise and
has better things to look at than a user interface. Every visual decision
answers to that scene: grey by default, colour only where colour carries a
safety meaning, and type sized so the one number that matters can be read at
arm's length without walking to the phone.

The system is deliberately quiet. There is no brand expression competing for
attention, because the three signal colours — green, red, amber — have fixed
operational meanings and must be impossible to mistake for decoration. When a
surface looks plain here, that is the design working, not the design missing.

Density is medium and consistent: one control height for the whole app, one
breakpoint, one type ramp. The interface should feel like a well-labelled panel
of switches, where nothing moves unless the state moved.

**Key Characteristics:**

- Neutral greys carry structure; hue is reserved for state
- One control height (40px pointer, 44px touch) governs every row
- Numbers are tabular so a readout never reflows as it counts
- Flat at rest — depth is a response, not an ornament
- Legibility in daylight outranks visual interest, always

## Colors

A near-monochrome grey system with three signal hues that mean specific things,
plus a blue for the ordinary "do the thing" action.

### Primary

- **Signal Blue** (`#2563eb`): the ordinary confirming action — Save, Add,
  Create. It is the only blue in the system and never carries state meaning; a
  blue button is something you press, not something the target is doing.

### Secondary

- **Indigo** (`#6366f1`): "this is the one running." Marks the active series in
  the timeline and the time badge on the run board. Used as a border and a tint,
  never as a large fill.
- **Deep Indigo** (`#4338ca`): the same signal where it has to be readable as
  text — the active series title on its tinted ground.

### Tertiary

- **Amber** (`#92400e` on `#fef3c7`): the advisory register. Startup issues,
  "no delay armed", anything the operator should notice but which does not stop
  the exercise.

### Neutral

- **Ink** (`#111827`): the countdown readout, and nothing else. It is the
  highest-contrast value in the system and reserved for the highest-stakes
  number.
- **Body Ink** (`#213547`): default text.
- **Strong Grey** (`#374151`): badge text, table headers.
- **Muted Grey** (`#6b7280`): secondary and supporting text — the single most
  used colour in the app.
- **Border Grey** (`#e5e7eb`) / **Strong Border** (`#d1d5db`): dividers, card
  edges, control outlines.
- **Surface** (`#ffffff`), **Sunken** (`#fafafa`), **Muted** (`#f3f4f6`): the
  three grounds. Layering is done with these, not with shadow.

### Dark theme

Settings offers System (the default, following `prefers-color-scheme`), Light
and Dark, kept in the browser like the server URL. The dark theme is the same
tokens with different values, never a second set of rules. It exists for the
range at night: a phone at arm's length under floodlights, where a white page
is the brightest thing in view.

It is composed, not inverted. Elevation runs the other way — the page is the
darkest ground (gray-900) and a card steps _up_ to gray-800, because a shadow
cannot be seen on a dark page. Text steps up the gray scale to stay above
4.5:1 on every ground it sits on, including `surface-muted`.

The signal hues split by job. A **fill** that carries white text (`go`,
`stop`, `action`, `accent-fill`, `warn-fill`) keeps its light value, because
white on it already clears 4.5:1 on any ground. An **ink** — the same hue used
as text or a line on the page (`stop-ink`, `shown-ink`, `warn-ink`,
`accent-deep`, `action-text`, `focus`) — moves to the 300–400 step, because
red-600 text on gray-800 does not. Tints drop to the 950 step. Green is still
shown, red still hidden, amber still no delay: the Three Signals Rule holds on
the dark ground by re-deriving each hue for contrast, not by flipping it.

`warn-tint-soft` (the Expert-mode ground) is stone-900 in the dark theme: amber
has no step dark enough to sit under a whole region without glowing.

| Token | Light | Dark |
| --- | --- | --- |
| `page` | `#ffffff` | `#111827` |
| `surface` | `#ffffff` | `#1f2937` |
| `surface-sunken` | `#fafafa` | `#111827` |
| `surface-muted` | `#f3f4f6` | `#374151` |
| `fill` | `#e5e7eb` | `#374151` |
| `fill-hover` | `#d1d5db` | `#4b5563` |
| `border` | `#e5e7eb` | `#374151` |
| `border-strong` | `#d1d5db` | `#4b5563` |
| `border-hover` | `#9ca3af` | `#6b7280` |
| `ink` | `#111827` | `#f9fafb` |
| `text` | `#213547` | `#e5e7eb` |
| `text-strong` | `#374151` | `#d1d5db` |
| `text-subtle` | `#4b5563` | `#d1d5db` |
| `text-muted` | `#6b7280` | `#9ca3af` |
| `on-fill` | `#ffffff` | `#ffffff` |
| `focus` | `#2563eb` | `#60a5fa` |
| `action` | `#2563eb` | `#2563eb` |
| `action-deep` | `#1d4ed8` | `#1d4ed8` |
| `action-text` | `#1d4ed8` | `#93c5fd` |
| `action-tint` | `#eff6ff` | `#172554` |
| `action-tint-strong` | `#dbeafe` | `#1e3a8a` |
| `accent` | `#6366f1` | `#818cf8` |
| `accent-deep` | `#4338ca` | `#a5b4fc` |
| `accent-ink` | `#312e81` | `#c7d2fe` |
| `accent-tint` | `#eef2ff` | `#1e1b4b` |
| `accent-border` | `#c7d2fe` | `#3730a3` |
| `accent-fill` | `#4338ca` | `#4338ca` |
| `accent-fill-deep` | `#3730a3` | `#4f46e5` |
| `shown` | `#16a34a` | `#22c55e` |
| `shown-ink` | `#15803d` | `#4ade80` |
| `shown-text` | `#14532d` | `#bbf7d0` |
| `shown-tint` | `#dcfce7` | `#052e16` |
| `shown-tint-soft` | `#f0fdf4` | `#052e16` |
| `go` | `#15803d` | `#15803d` |
| `go-deep` | `#166534` | `#166534` |
| `stop` | `#dc2626` | `#dc2626` |
| `stop-deep` | `#b91c1c` | `#b91c1c` |
| `stop-ink` | `#dc2626` | `#f87171` |
| `stop-ink-deep` | `#b91c1c` | `#fca5a5` |
| `stop-text` | `#7f1d1d` | `#fecaca` |
| `stop-tint` | `#fee2e2` | `#450a0a` |
| `stop-tint-soft` | `#fef2f2` | `#450a0a` |
| `stop-border` | `#fca5a5` | `#991b1b` |
| `warn` | `#92400e` | `#fcd34d` |
| `warn-ink` | `#b45309` | `#fbbf24` |
| `warn-fill` | `#b45309` | `#b45309` |
| `warn-fill-deep` | `#92400e` | `#92400e` |
| `warn-tint` | `#fef3c7` | `#451a03` |
| `warn-tint-strong` | `#fde68a` | `#78350f` |
| `warn-tint-soft` | `#fffbeb` | `#1c1917` |
| `warn-border` | `#fcd34d` | `#b45309` |

### Named Rules

**The Three Signals Rule.** Green means the target is shown, red means it is
hidden, amber means no delay is armed. No other element may use those hues for
any other purpose — not for a decorative accent, not for a chart, not for a
brand flourish. If a new state needs a colour and is not one of those three
things, it uses indigo or a grey.

**The One Family Rule.** The palette is the Tailwind scale, and only the
Tailwind scale. Two earlier families used to be mixed in — the Vite starter
purple (`#646cff`, never chosen, just the `npm create vite` default) and
Material's greens and reds on the timeline event boxes. Both are gone. The
purple mattered because it sits close enough to the accent indigo to look
intentional and far enough to look wrong beside it, which is the worst distance
for two colours to be.

**The Readable Signal Rule.** Signal colours are chosen for contrast, not for
brightness. White text sits on green-700 (`#15803d`), never green-600, because
white on green-600 measures 3.3:1 and fails AA. Any new coloured surface must
clear 4.5:1 for its text before it ships.

## Typography

**Body Font:** Inter (with system-ui, Avenir, Helvetica, Arial fallbacks)
**Readout Font:** the platform system stack (`-apple-system`,
`BlinkMacSystemFont`, `Segoe UI`, Roboto), used only for the countdown so the
digits render in the device's most familiar, most hinted numerals.

**Character:** plain, neutral, unstyled. The type is not doing expressive work;
it is doing legibility work. Weight and size carry the hierarchy, and there are
only three weights in the whole system.

### Hierarchy

- **Display** (700, `clamp(4.5rem, 24vw, 7rem)`, line-height 1): the countdown
  digits alone. Scales _up_ with the viewport rather than down, and uses
  tabular numerals so the box does not resize as 10 becomes 9.
- **Headline** (600, 1.5rem): page titles.
- **Title** (600, 1.1rem–1.25rem): card and section headings, series titles.
- **Body** (400, 0.9rem): the workhorse. Table cells, descriptions, controls.
- **Label** (600, 0.75rem, 0.05em, uppercase): badge captions and field labels.
  Uppercase is the tell that something is a label and not content.
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

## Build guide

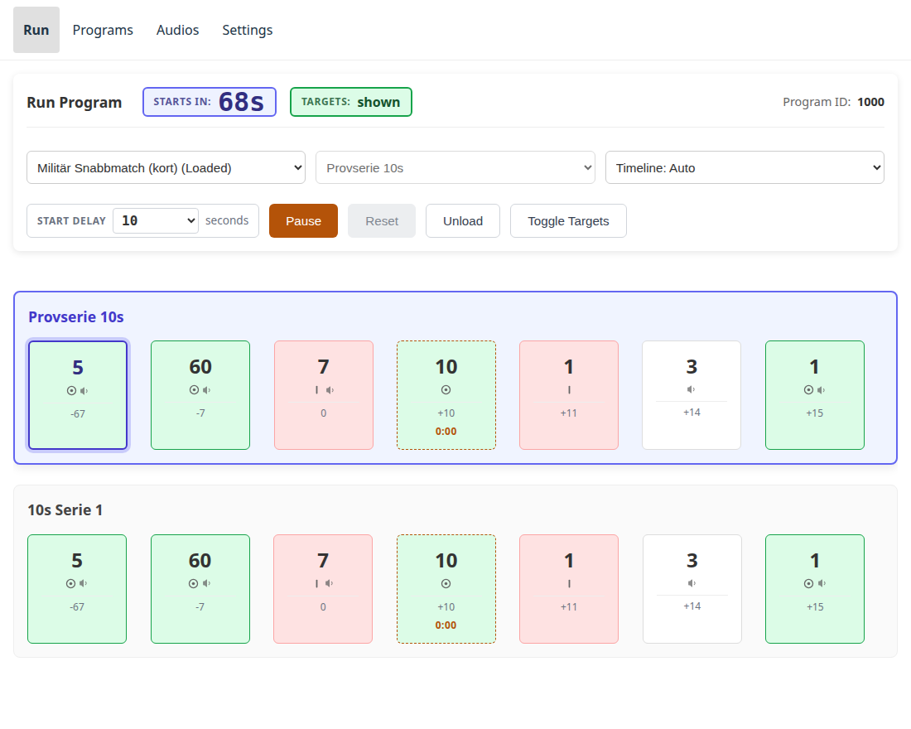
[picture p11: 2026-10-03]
docs/site/img/tutorial-countdown.png

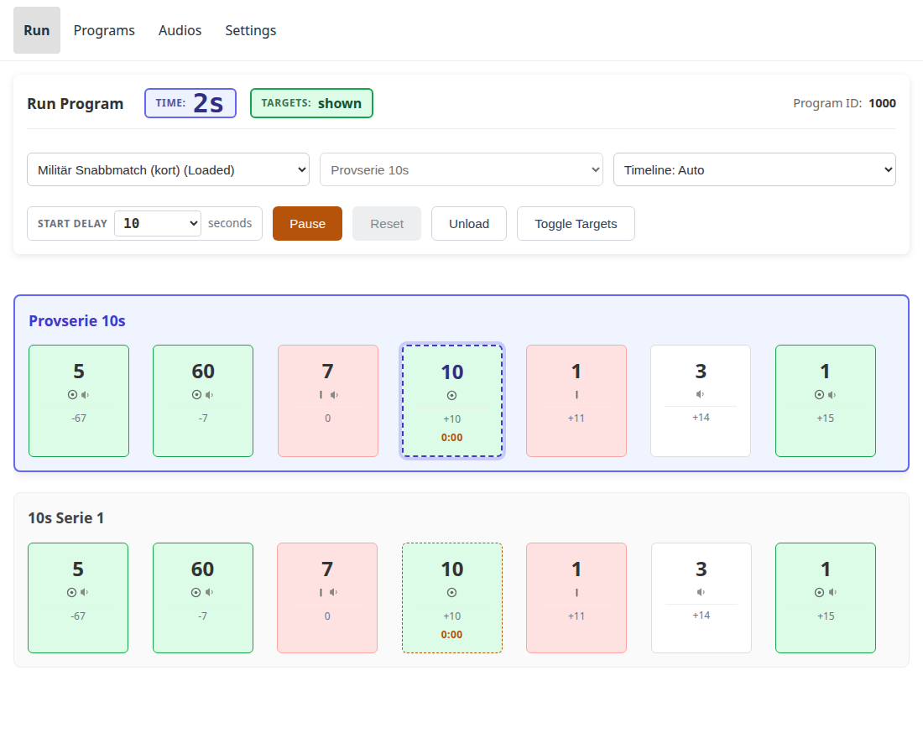
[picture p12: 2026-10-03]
docs/site/img/tutorial-shooting.png

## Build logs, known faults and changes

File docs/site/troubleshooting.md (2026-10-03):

# Troubleshooting

Start with the [status LED](status-led.md) — it is the only feedback the
device gives when no browser is open, and it distinguishes "still connecting"
from "never connected" at a glance. Most of what follows starts by reading it.

## Device not found

| LED | Meaning | What to do |
|---|---|---|
| Blinking red | Still trying to join a network | Wait — nothing to fix yet |
| Solid red | Gave up joining; the setup portal should be up | See [Connecting](connecting.md#the-setup-portal) |
| Blue | On the setup portal's own network | It has no range network yet — go through setup |
| Yellow, and staying that way | On the network, but the web server has not come up | The network side is fine; this is a device fault, not a connection one |
| Green | Serving | The device is reachable — if the browser still cannot reach it, see below |

If the LED is green but `http://revolve-now.local` will not load, the
network is not resolving the mDNS name for you — try the device's IP address
directly instead (see [Connecting](connecting.md#finding-the-device)). Confirm
the browser is actually on the same network as the device, not still on
mobile data or a previous WiFi.

## Targets not moving

- Try **Toggle Targets** on the Run page. If that does not move the targets
  either, the problem is not the loaded program — check power to the target
  system and the DB9 connection (see [Hardware](hardware.md)).
- If Toggle Targets works but a program does not move them, check the
  program's timeline: an event with no show/hide command is a timed pause by
  design, not a fault.
- If the targets move, but the wrong way — showing when they should hide, or
  the reverse — that is a build-time wiring setting, not something fixable
  from the web app. Report it rather than rewiring anything.

## No audio

- Confirm the amplifier is powered and connected — the device has no way to
  detect that on its own.
- Some devices are built with audio hardware disabled entirely; a target that
  only turns, with no sound, is a supported configuration on those. If that is
  the case for this device, there is nothing to fix.
- A clip that fails to play (missing, or not a playable file) is reported by
  the device as a **backend issue** banner — currently surfaced on the Audios
  page, not the Run page, so check there if a run went quiet. <!-- TODO: confirm whether this should also surface on the Run page -->
- The run itself is unaffected by a clip failing to play: it carries on
  silently through that event rather than stopping.

## "Stop" says the program is not running (400)

`POST /programs/stop` — the Pause action — answers `400` when nothing is
running. This is expected, not a fault, and shows up in one case an operator
will actually hit: **pressing Pause after a series has already finished on its
own** — a series that runs to the end stops itself, so there is nothing left
to pause. If another series follows, the device has already selected it and
is waiting at its first event; press Start to run it. If that was the last
series, the program has finished — Start would replay it from the beginning,
or Unload to pick something else.

## Sending a fault report

When the device has misbehaved and nobody at the range can say why, send a
**troubleshooting bundle** rather than a description of the symptoms. It is one
zip file holding what the device knows about itself — its version, how much
memory and storage it has left, why it last restarted, and what it complained
about at startup — plus, if it crashed, the crash dump itself.

The crash dump is the part that matters, and the part that used to need a cable
and a laptop with developer tools on it. It also has to be read against the
exact firmware that produced it, which stops being the firmware on the board as
soon as somebody updates it — so the bundle carries that identity alongside the
dump.

**To download one:**

1. Press the device's **BOOT** button — the small button next to the USB
   sockets, marked `BOOT` or `FLASH` — **three times within ten seconds.**
2. Open the **Expert mode** tab that appears in the web app, and scroll to
   **Troubleshooting** at the bottom.
3. Press **Download troubleshooting bundle** and attach the file to your
   message.

The tab is only there for five minutes after those three presses, and it does
not appear at all while a program is running. If it is missing, press the button
three times again. [Expert mode](expert-mode.md) covers what else is on it.

!!! warning "Who you can send it to"

    A crash dump is a copy of what was in the device's memory at the moment it
    failed, and that can include **the WiFi password**. That is why downloading
    one needs somebody standing at the board pressing its button, and it is why
    the file should go to somebody you would tell the password to.

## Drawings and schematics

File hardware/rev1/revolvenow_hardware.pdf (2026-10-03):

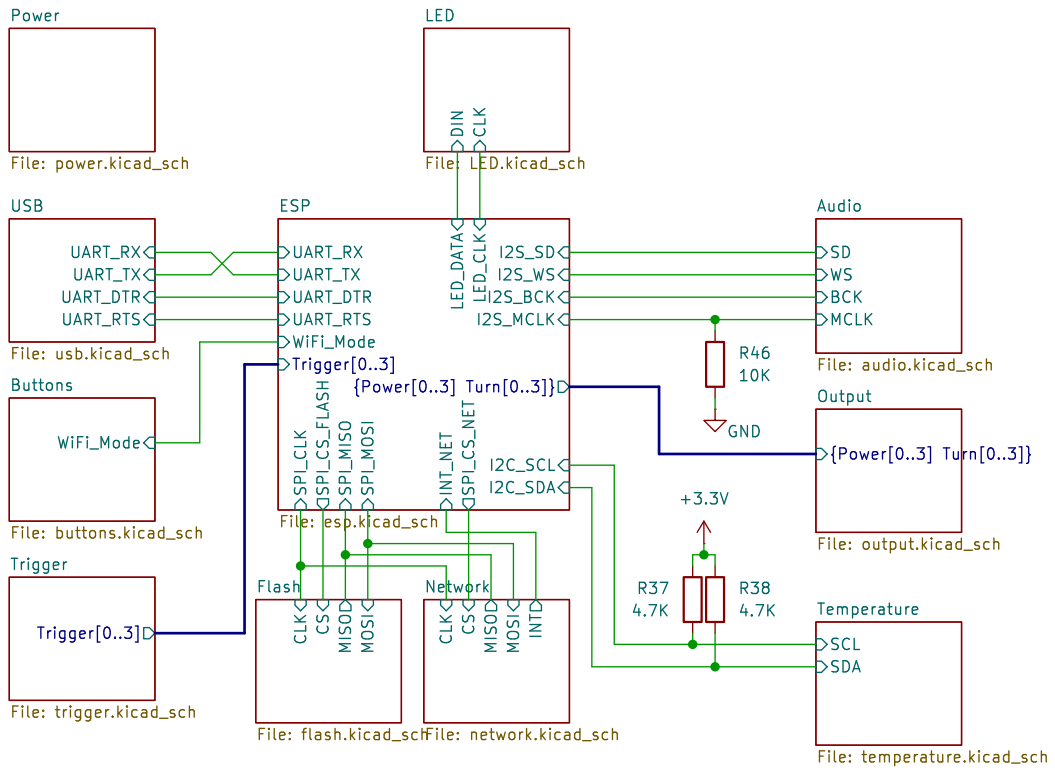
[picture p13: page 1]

File: LED.kicad_sch CLKCS MISO MOSI Flash File: flash.kicad_sch

Output File: output.kicad_sch BCK MCLK

Temperature File: temperature.kicad_sch WiFi_Mode Buttons File: buttons.kicad_sch Trigger[0..3]

Id: 1/12 Title: File: revolvenow_hardware.kicad_sch Sheet: /

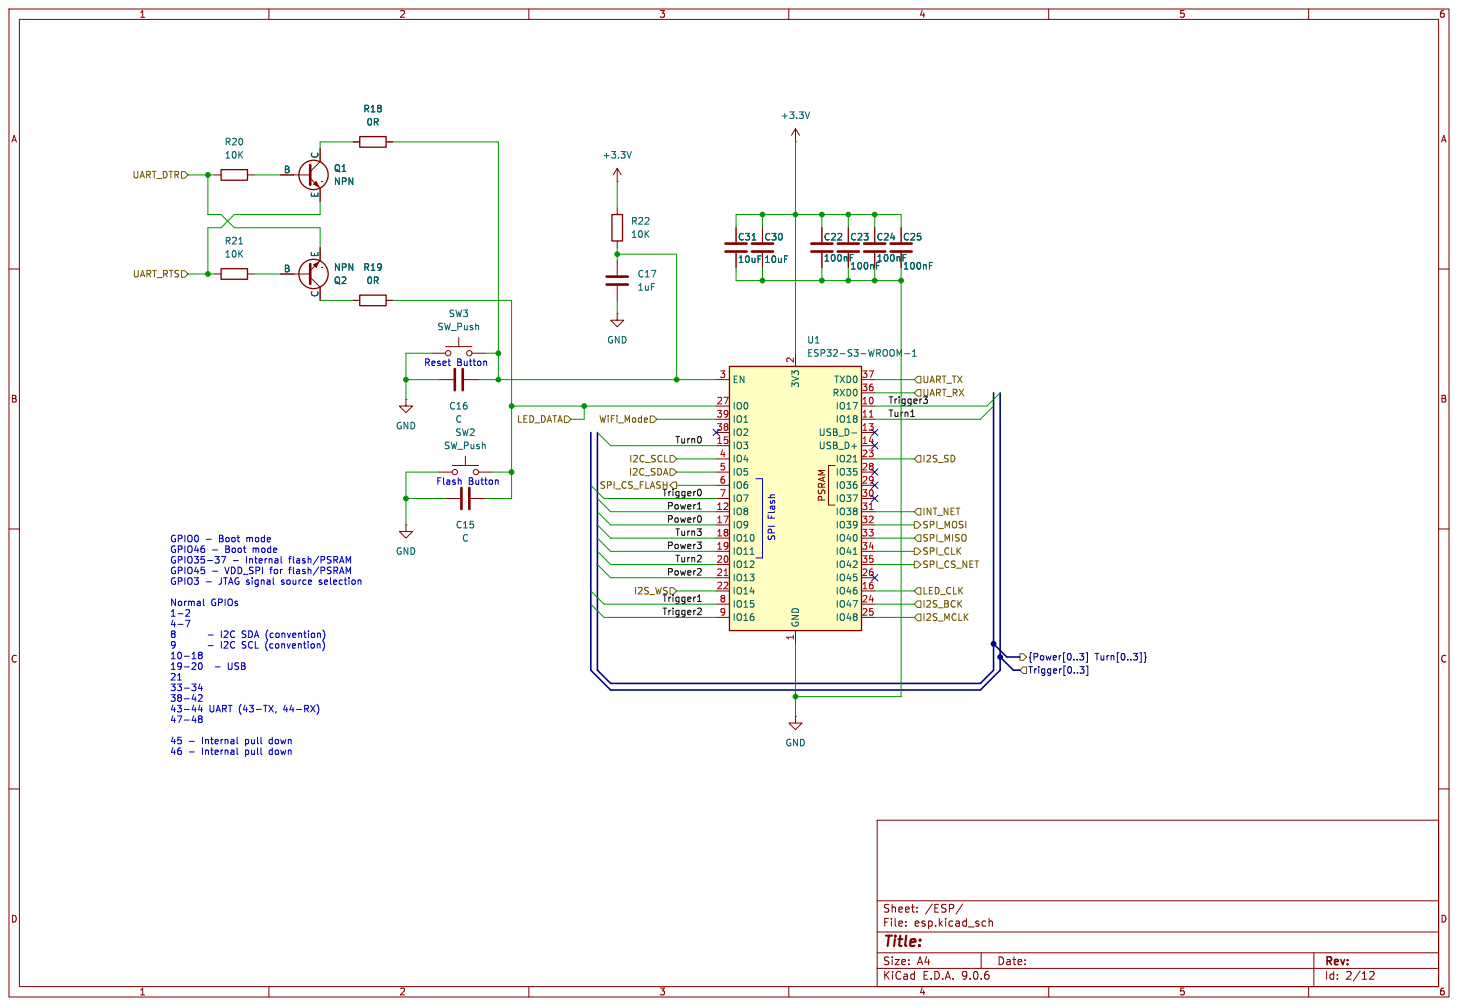
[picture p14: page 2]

GPIO45 - VDD_SPI for flash/PSRAM
GPIO3 - JTAG signal source selection Normal GPIOs 1-2

Id: 2/12 Title: File: esp.kicad_sch Sheet: /ESP/

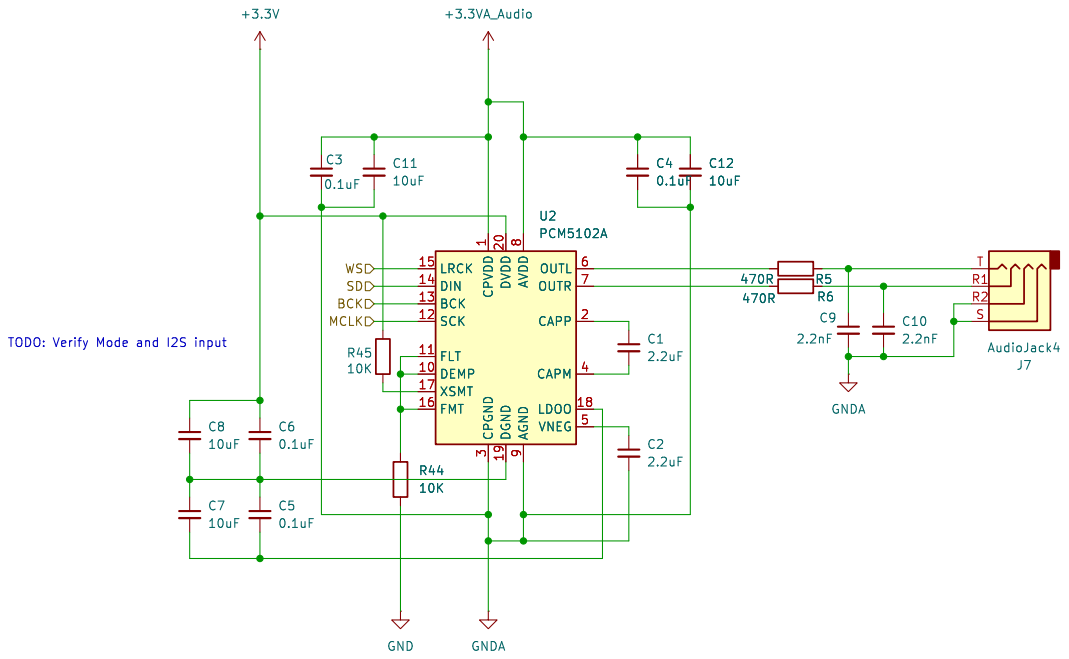
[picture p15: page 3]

9 OUTL 6 OUTR 7 CAPP 2 CAPM 4

Id: 3/12 Title: File: audio.kicad_sch Sheet: /Audio/

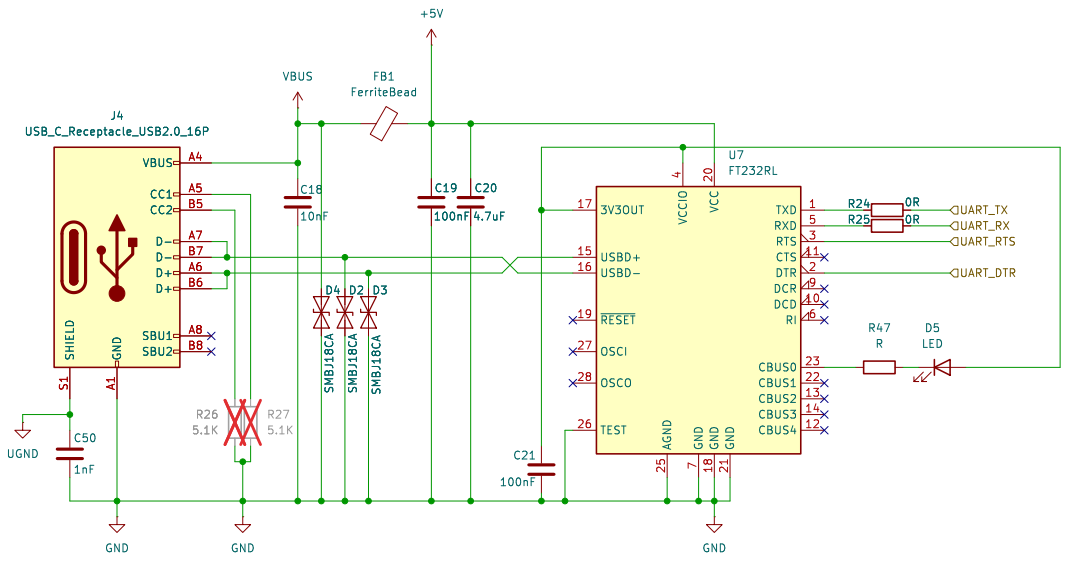
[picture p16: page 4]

7 VCC 20 GND 18 GND 21 TXD 1 RXD 5 RTS 3 CTS 11 DTR 2 DCR 9 DCD 10 RI 6 CBUS0 23 CBUS1 22 CBUS2 13 CBUS3 14 CBUS4 12 U7 FT232RL R24 0R

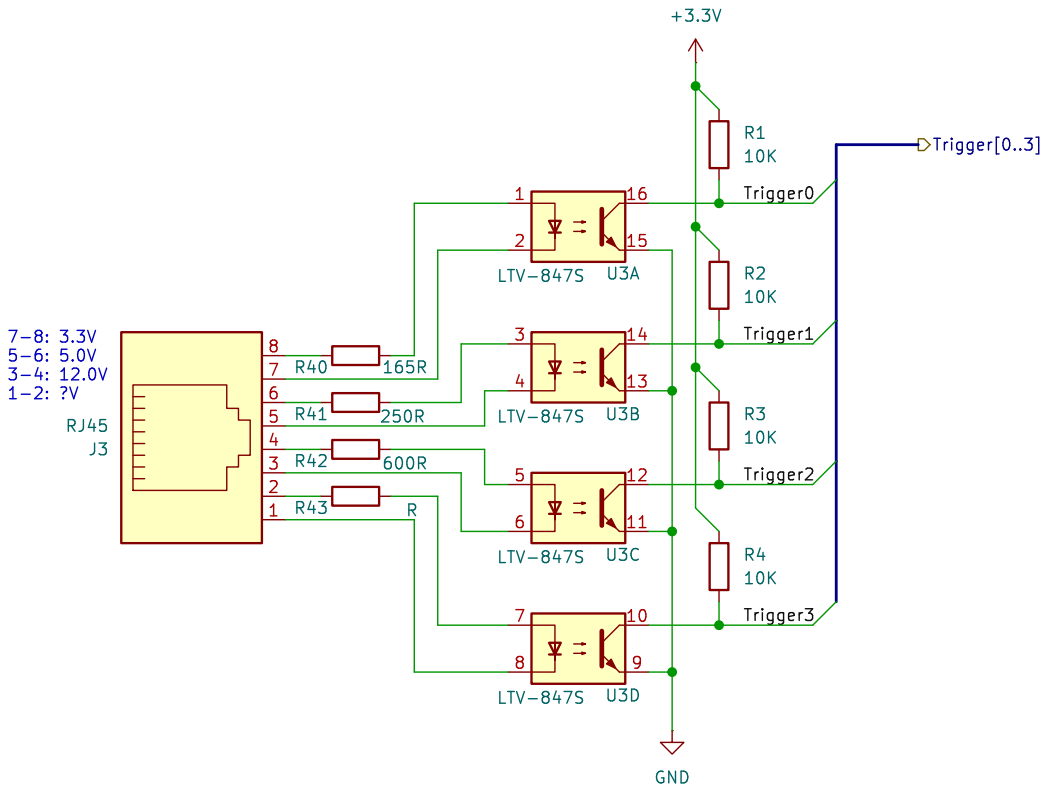
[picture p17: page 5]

Id: 5/12 Title: File: trigger.kicad_sch Sheet: /Trigger/

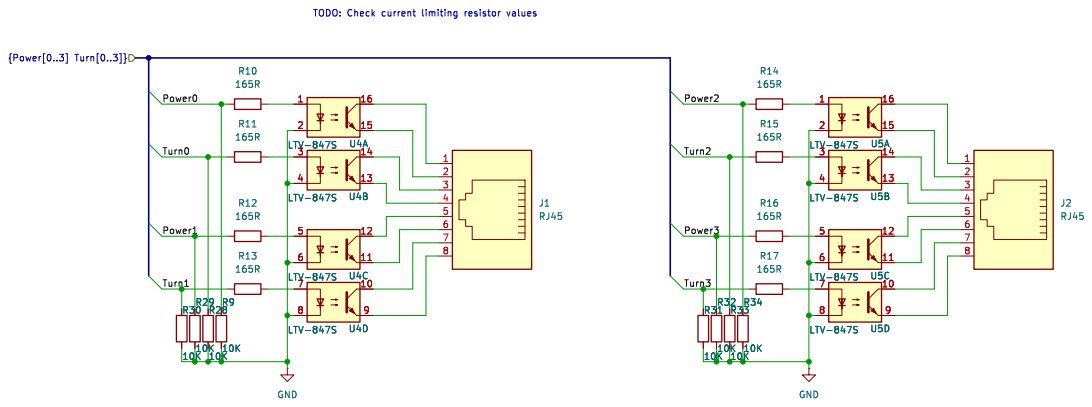
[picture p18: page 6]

Id: 6/12 Title: File: output.kicad_sch Sheet: /Output/

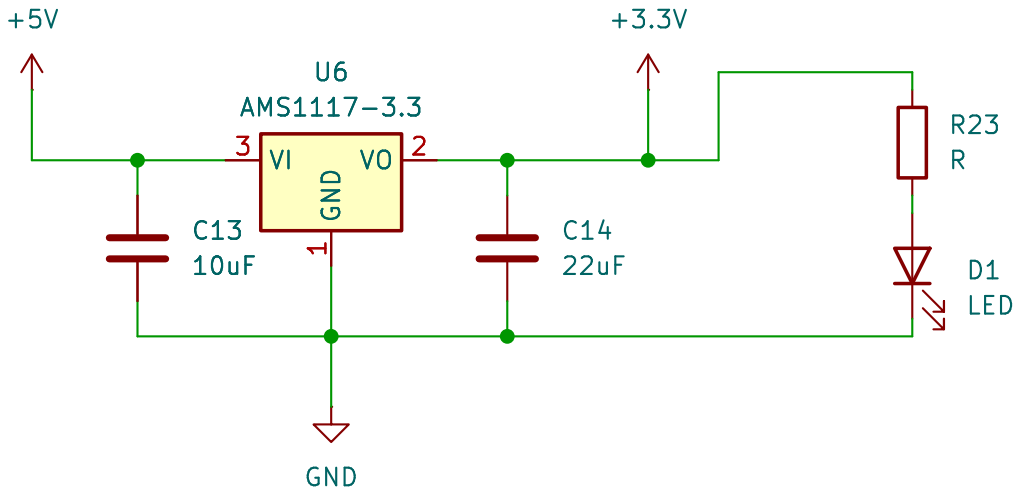
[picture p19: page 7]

Id: 7/12 Title: File: power.kicad_sch Sheet: /Power/

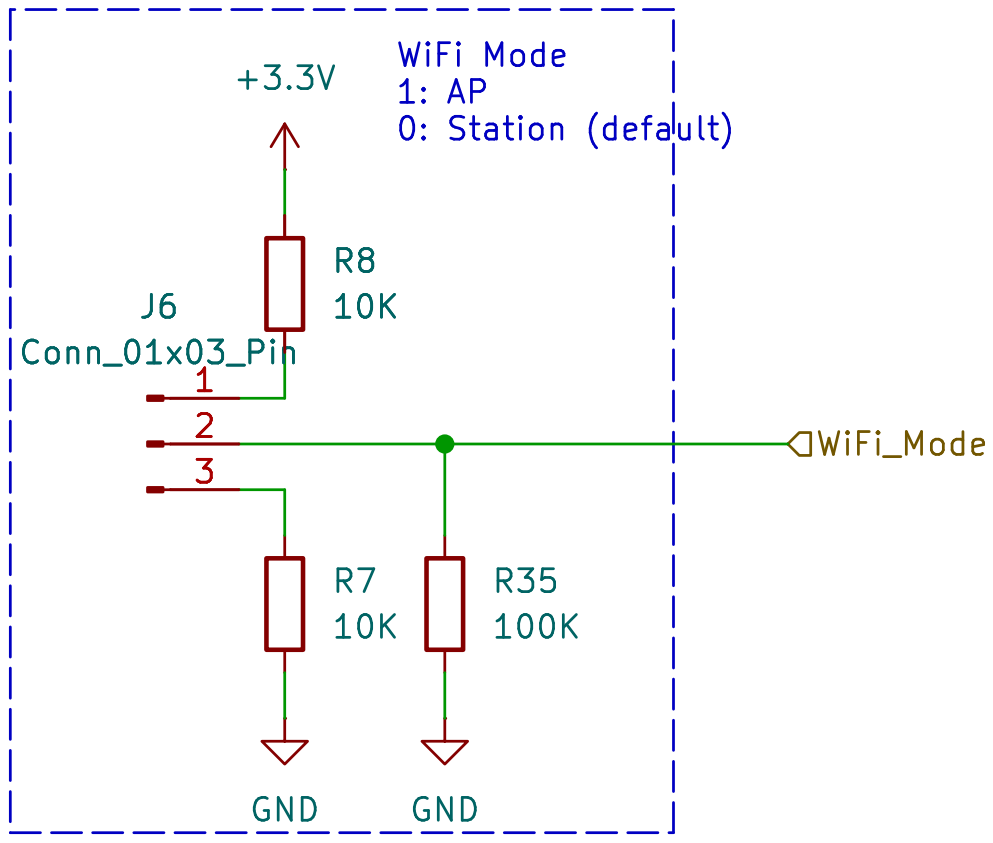
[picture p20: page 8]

Id: 8/12 Title: File: buttons.kicad_sch Sheet: /Buttons/

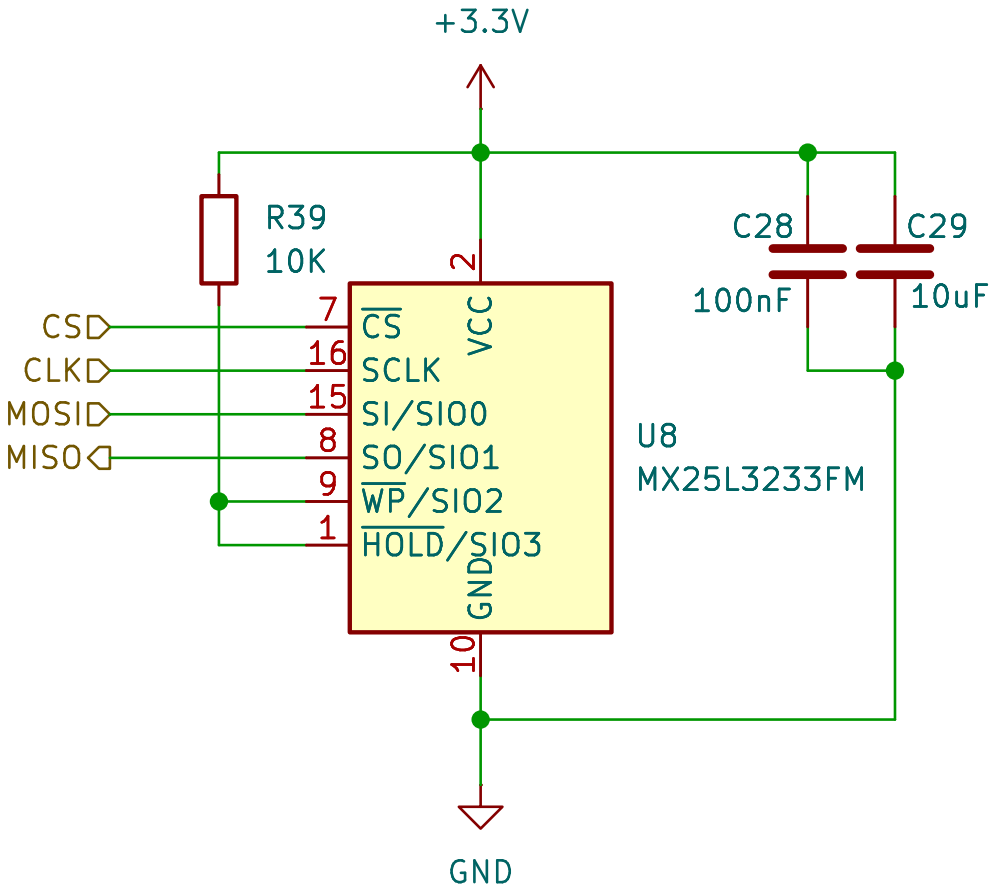
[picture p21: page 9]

Id: 9/12 Title: File: flash.kicad_sch Sheet: /Flash/

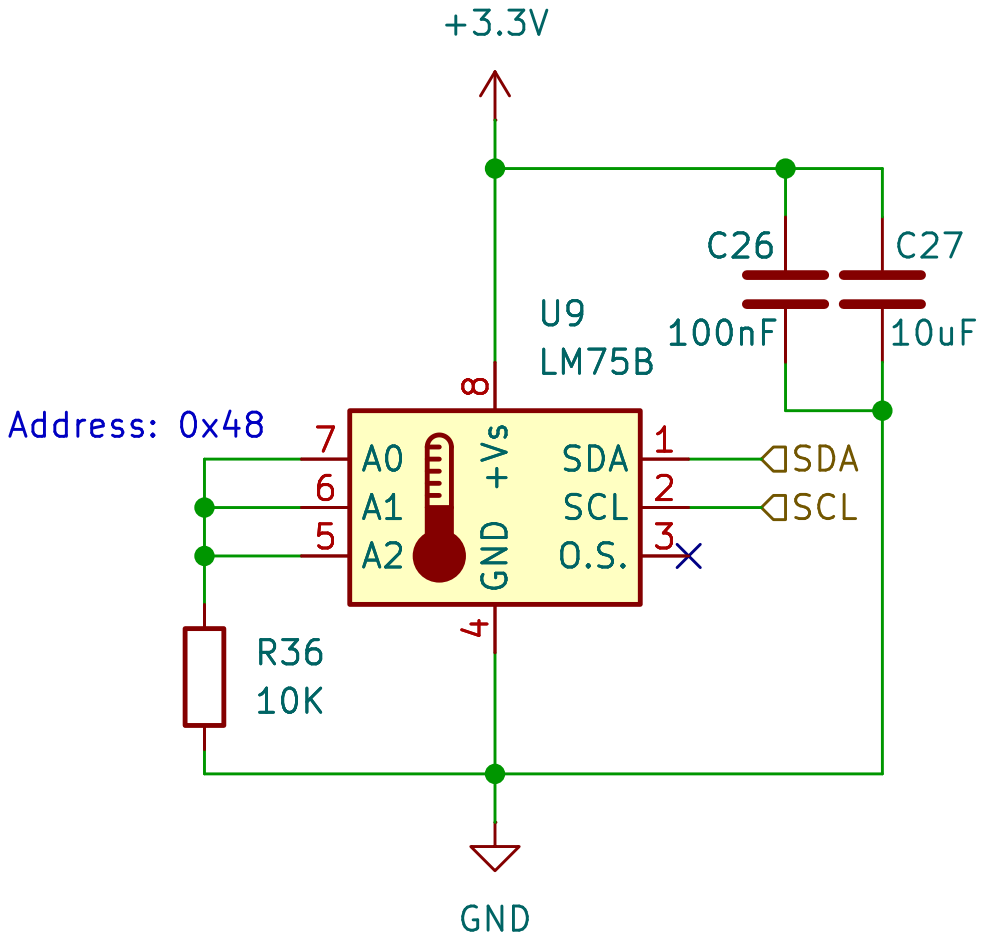
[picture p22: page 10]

Id: 10/12 Title: File: temperature.kicad_sch Sheet: /Temperature/

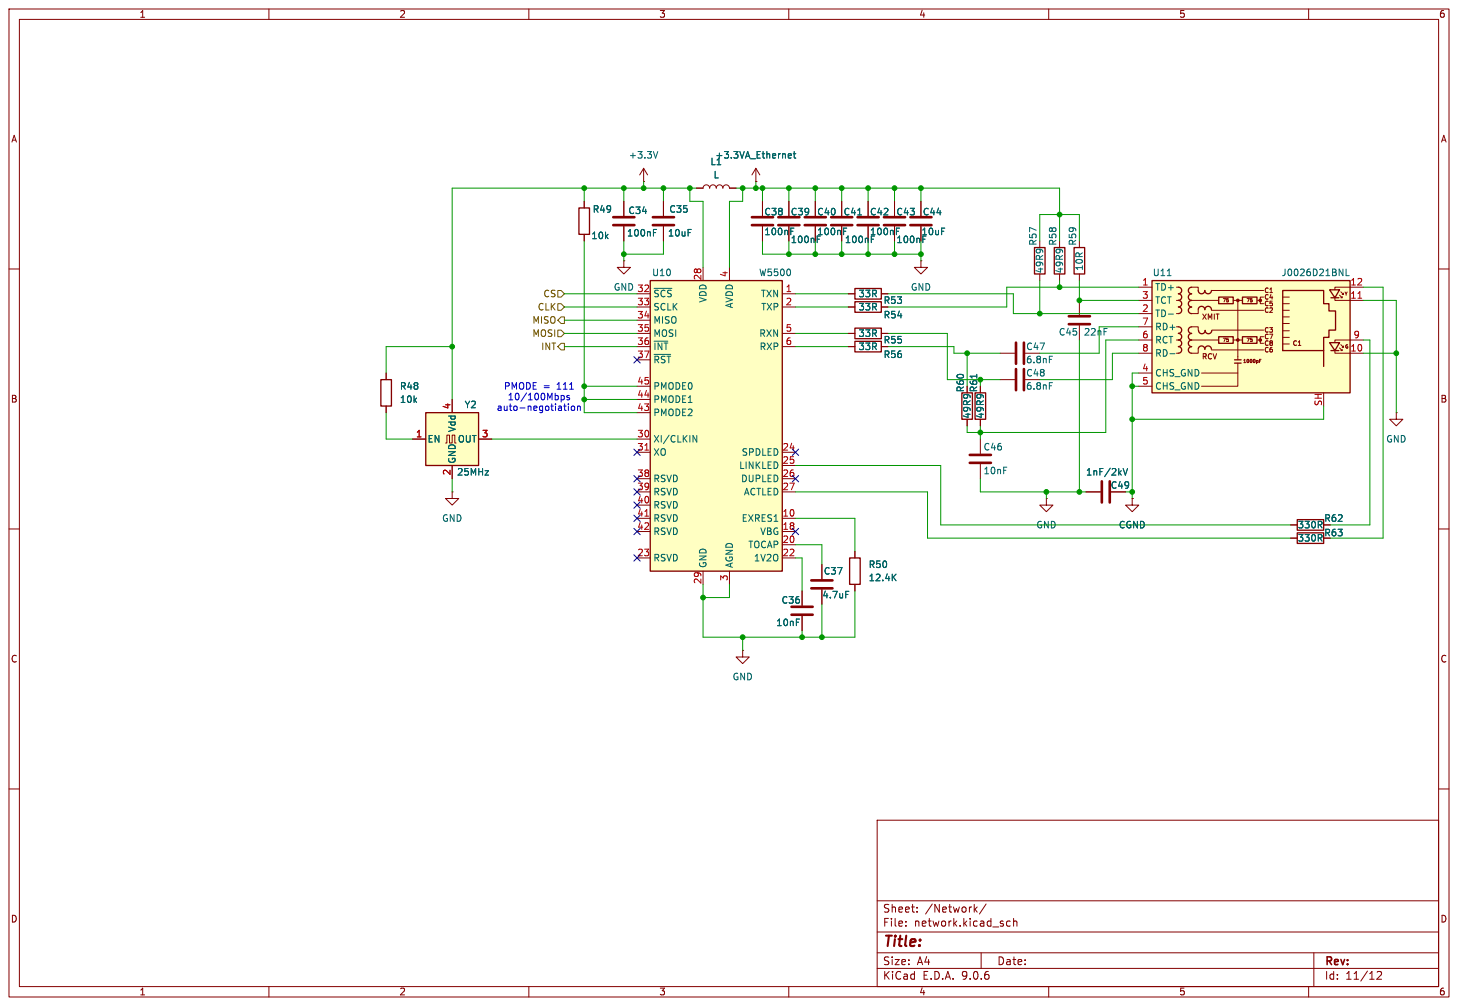
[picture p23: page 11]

3 TXN 1 TXP 2 RXN 5 RXP 6 SPDLED 24

INT MOSI CS MISO
CLK

Id: 11/12 Title: File: network.kicad_sch Sheet: /Network/

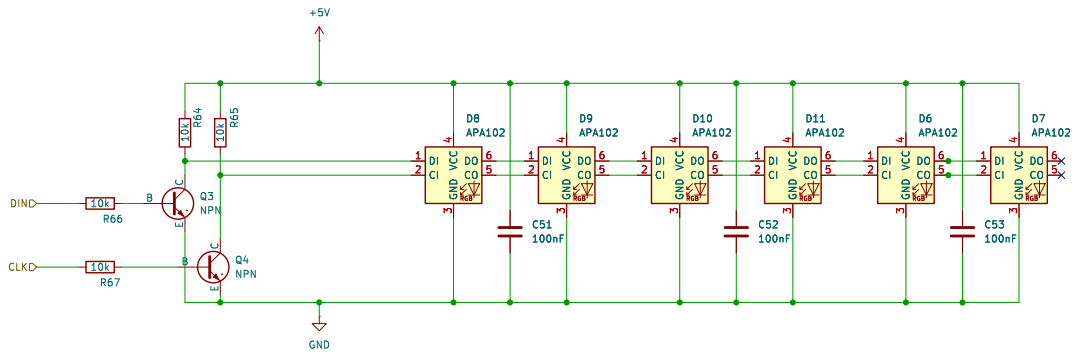
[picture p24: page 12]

3 DO 6 CO 5 D9APA102 DI 1 CI 2 VCC

3 DO 6 CO 5 D7APA102 DI 1 CI 2 VCC

Id: 12/12 Title: File: LED.kicad_sch Sheet: /LED/

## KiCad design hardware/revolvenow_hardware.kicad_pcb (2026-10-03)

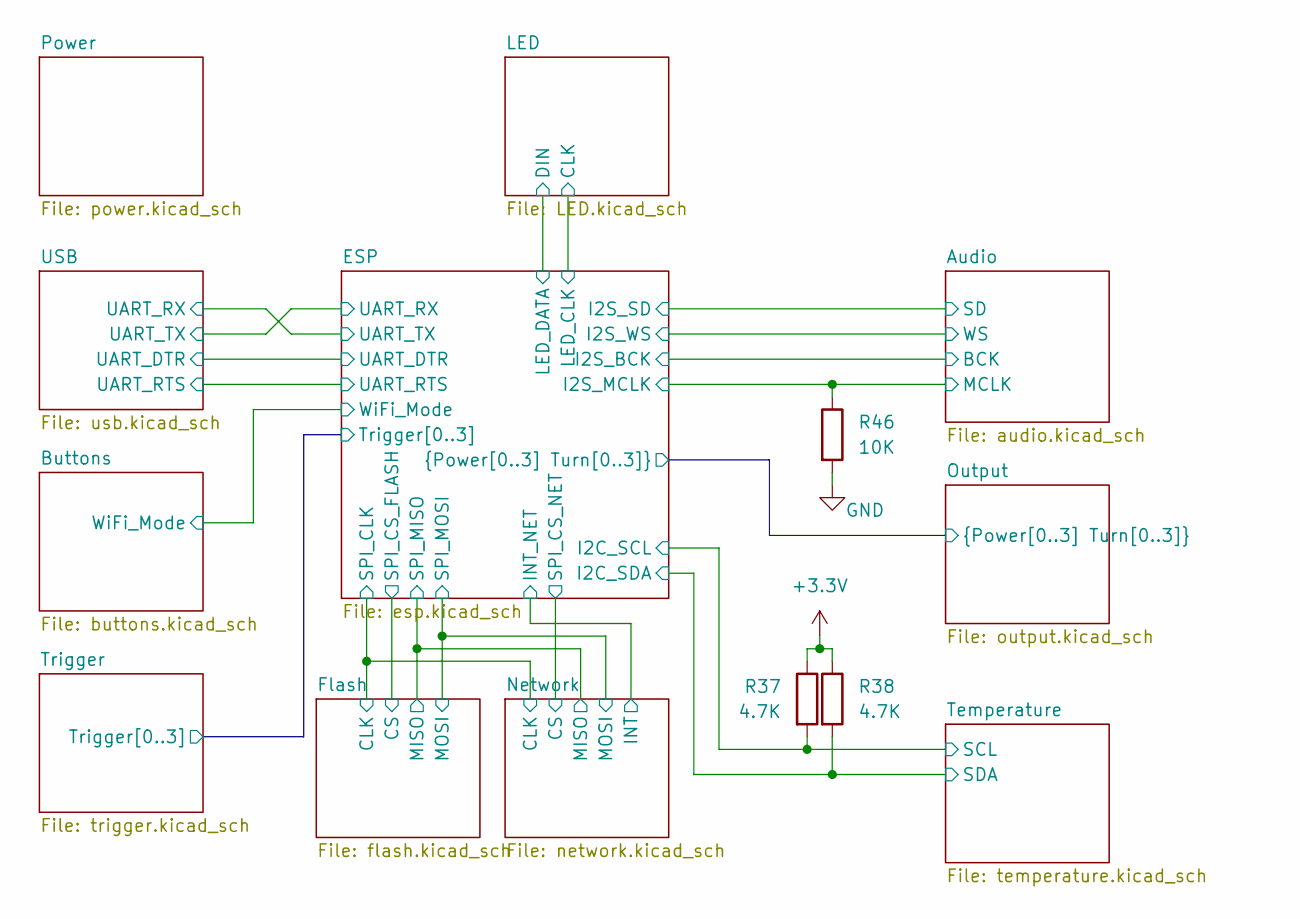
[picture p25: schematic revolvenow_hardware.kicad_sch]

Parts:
R37, R38: 4.7K; R_0603_1608Metric_Pad0.98x0.95mm_HandSolder
R46: 10K; R_0603_1608Metric_Pad0.98x0.95mm_HandSolder

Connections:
+3.3V: R37.1, R38.1; also elsewhere on the board
/Audio/MCLK: R46.1; also elsewhere on the board
/ESP/I2C_SCL: R37.2; also elsewhere on the board
/ESP/I2C_SDA: R38.2; also elsewhere on the board
GND: R46.2; also elsewhere on the board

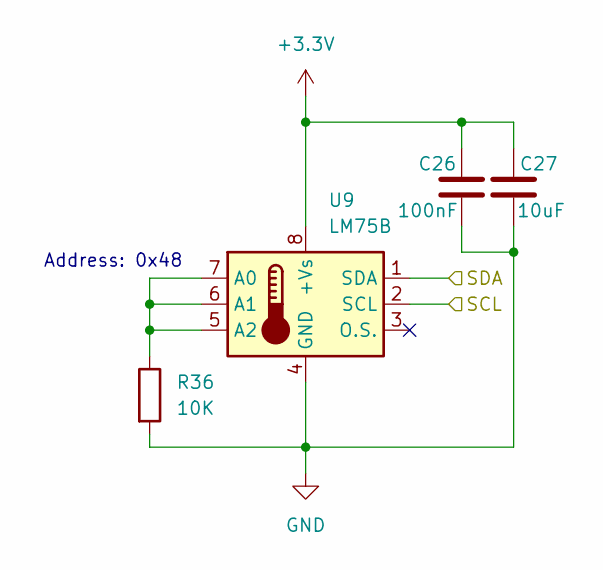
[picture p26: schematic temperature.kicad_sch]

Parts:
C26: 100nF; C_0603_1608Metric_Pad1.08x0.95mm_HandSolder
C27: 10uF; C_0603_1608Metric_Pad1.08x0.95mm_HandSolder
R36: 10K; R_0603_1608Metric_Pad0.98x0.95mm_HandSolder
U9: LM75B; SOIC-8_3.9x4.9mm_P1.27mm

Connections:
+3.3V: C26.1, C27.1, U9.8 (+Vs); also elsewhere on the board
/ESP/I2C_SCL: U9.2 (SCL); also elsewhere on the board
/ESP/I2C_SDA: U9.1 (SDA); also elsewhere on the board
GND: C26.2, C27.2, R36.2, U9.4 (GND); also elsewhere on the board
unnamed: R36.1, U9.5 (A2), U9.6 (A1), U9.7 (A0)

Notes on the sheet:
Address: 0x48

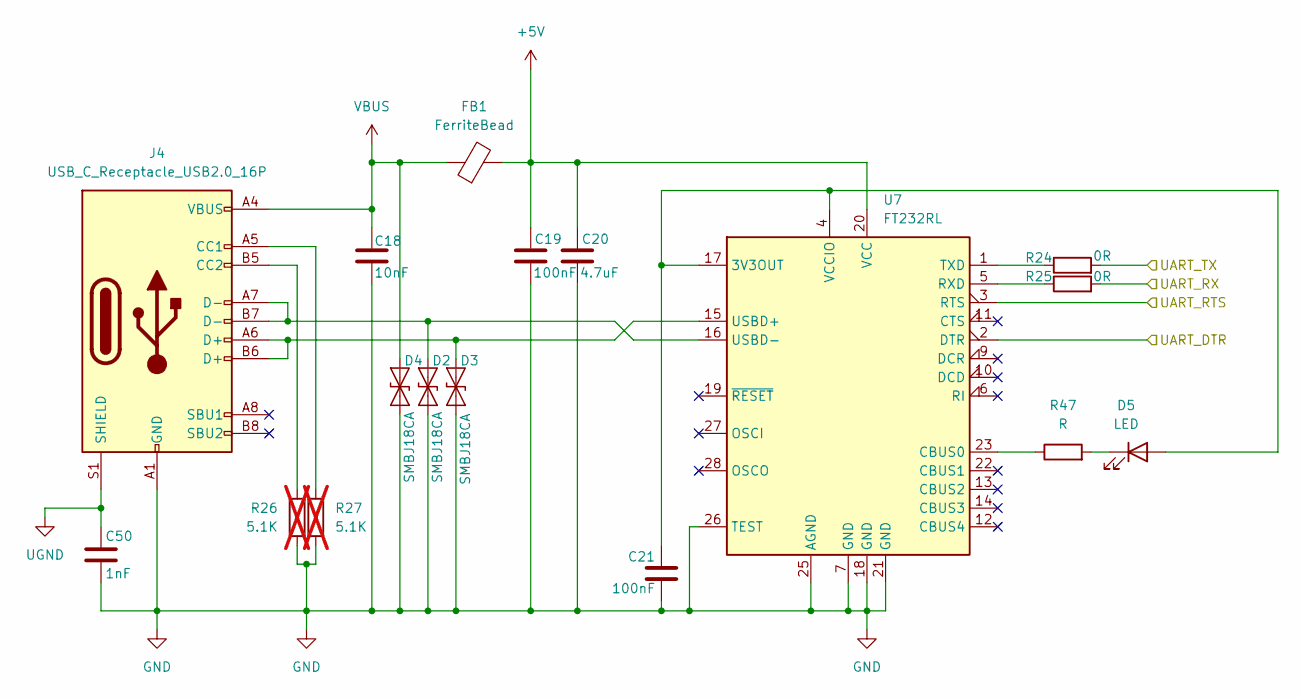
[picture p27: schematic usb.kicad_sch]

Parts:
C18: 10nF; C_0603_1608Metric_Pad1.08x0.95mm_HandSolder
C19, C21: 100nF; C_0603_1608Metric_Pad1.08x0.95mm_HandSolder
C20: 4.7uF; C_0603_1608Metric_Pad1.08x0.95mm_HandSolder
C50: 1nF; C_0603_1608Metric_Pad1.08x0.95mm_HandSolder
D2, D3, D4: SMBJ18CA; D_SMB_Handsoldering
D5: LED; LED_0603_1608Metric_Pad1.05x0.95mm_HandSolder
FB1: FerriteBead; R_0805_2012Metric_Pad1.20x1.40mm_HandSolder
J4: USB_C_Receptacle_USB2.0_16P; USB Type-C-02
R24, R25: 0R; R_0603_1608Metric_Pad0.98x0.95mm_HandSolder
R26, R27: 5.1K; R_0603_1608Metric_Pad0.98x0.95mm_HandSolder; not fitted
R47: R; R_0603_1608Metric_Pad0.98x0.95mm_HandSolder
U7: FT232RL; SSOP-28_5.3x10.2mm_P0.65mm

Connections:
+5V: C19.1, C20.1, FB1.2, U7.20 (VCC); also elsewhere on the board
/ESP/UART_DTR: U7.2 (DTR); also elsewhere on the board
/ESP/UART_RTS: U7.3 (RTS); also elsewhere on the board
/ESP/UART_RX: R24.2; also elsewhere on the board
/ESP/UART_TX: R25.2; also elsewhere on the board
GND: C18.2, C19.2, C20.2, C21.2, C50.1, D2.1 (A1), D3.1 (A1), D4.1 (A1), J4.A1 (GND), J4.A12 (GND), J4.B1 (GND), J4.B12 (GND), R26.2, R27.2, U7.7 (GND), U7.18 (GND), U7.21 (GND), U7.25 (AGND), U7.26 (TEST); also elsewhere on the board
unnamed: D2.2 (A2), J4.A7 (D-), J4.B7 (D-), U7.16 (USBD-)
unnamed: D3.2 (A2), J4.A6 (D+), J4.B6 (D+), U7.15 (USBD+)
unnamed: C21.1, D5.2 (A), U7.4 (VCCIO), U7.17 (3V3OUT)
unnamed: D5.1 (K), R47.2
unnamed: J4.A5 (CC1), R27.1
unnamed: J4.B5 (CC2), R26.1
unnamed: R47.1, U7.23 (CBUS0)
unnamed: R25.1, U7.5 (RXD)
unnamed: R24.1, U7.1 (TXD)
UGND: C50.2, J4.S1 (SHIELD)
VBUS: C18.1, D4.2 (A2), FB1.1, J4.A4 (VBUS), J4.A9 (VBUS), J4.B4 (VBUS), J4.B9 (VBUS)

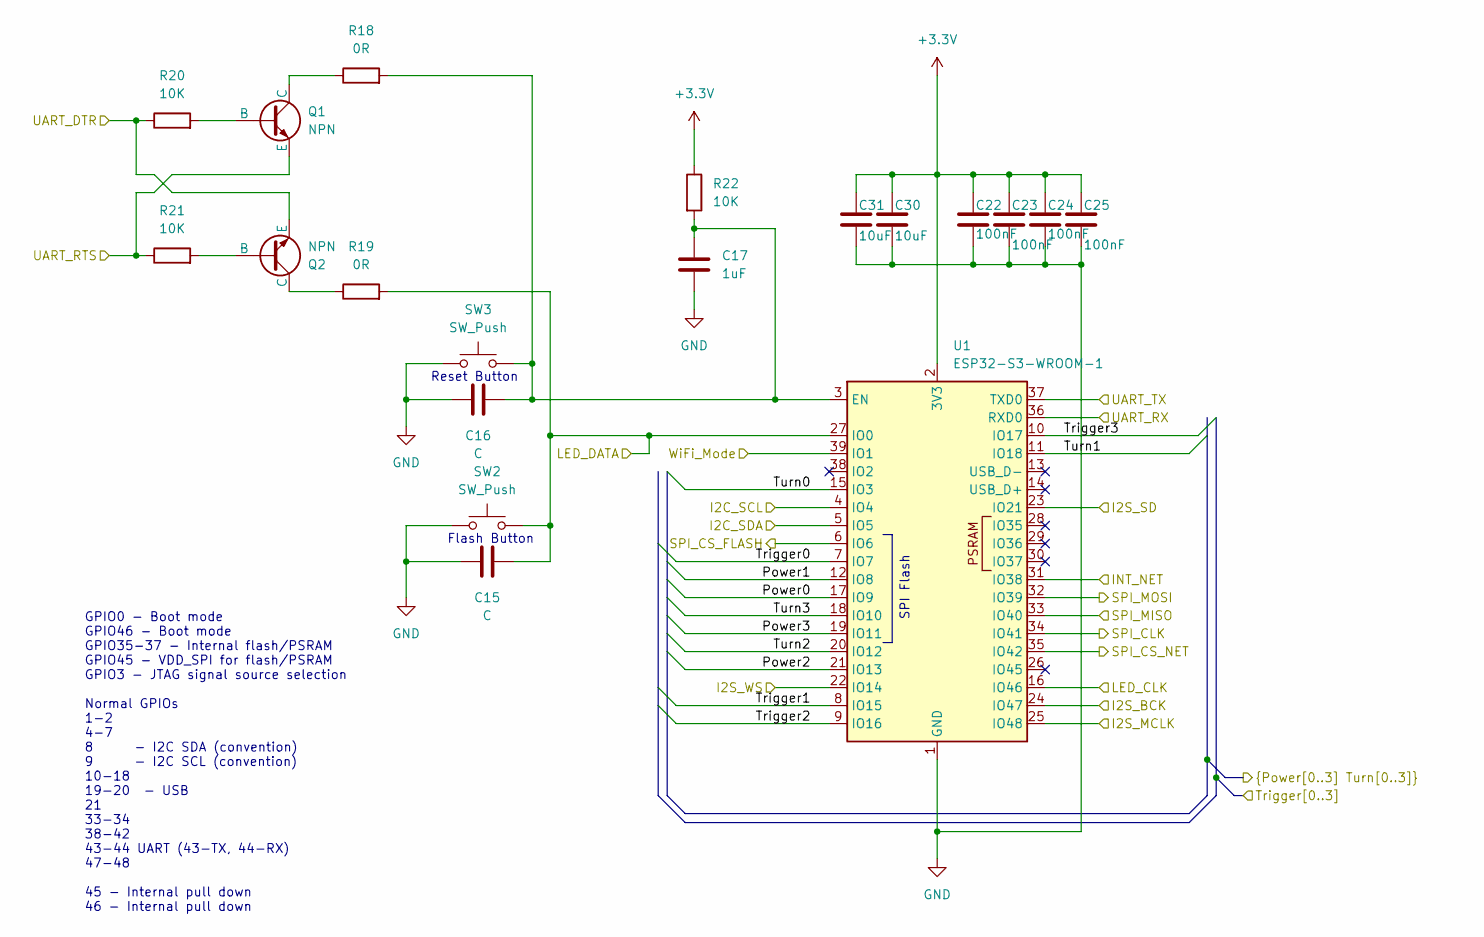
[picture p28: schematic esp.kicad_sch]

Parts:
C15, C16: C; C_0603_1608Metric_Pad1.08x0.95mm_HandSolder
C17: 1uF; C_0603_1608Metric_Pad1.08x0.95mm_HandSolder
C22, C23, C24, C25: 100nF; C_0603_1608Metric_Pad1.08x0.95mm_HandSolder
C30, C31: 10uF; C_0603_1608Metric_Pad1.08x0.95mm_HandSolder
Q1, Q2: NPN; SOT-23_Handsoldering
R18, R19: 0R; R_0603_1608Metric_Pad0.98x0.95mm_HandSolder
R20, R21, R22: 10K; R_0603_1608Metric_Pad0.98x0.95mm_HandSolder
SW2, SW3: SW_Push; SW_SPST_PTS645Sx43SMTR92
U1: ESP32-S3-WROOM-1

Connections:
+3.3V: C22.1, C23.1, C24.1, C25.1, C30.1, C31.1, R22.1, U1.2 (3V3); also elsewhere on the board
/Audio/BCK: U1.24 (IO47); also elsewhere on the board
/Audio/MCLK: U1.25 (IO48); also elsewhere on the board
/Audio/SD: U1.23 (IO21); also elsewhere on the board
/Audio/WS: U1.22 (IO14); also elsewhere on the board
/Buttons/WiFi_Mode: U1.39 (IO1); also elsewhere on the board
/ESP/I2C_SCL: U1.4 (IO4); also elsewhere on the board
/ESP/I2C_SDA: U1.5 (IO5); also elsewhere on the board
/ESP/INT_NET: U1.31 (IO38); also elsewhere on the board
/ESP/LED_CLK: U1.16 (IO46); also elsewhere on the board
/ESP/LED_DATA: C15.2, R19.2, SW2.2, U1.27 (IO0); also elsewhere on the board
/ESP/Power0: U1.17 (IO9); also elsewhere on the board
/ESP/Power1: U1.12 (IO8); also elsewhere on the board
/ESP/Power2: U1.21 (IO13); also elsewhere on the board
/ESP/Power3: U1.19 (IO11); also elsewhere on the board
/ESP/SPI_CLK: U1.34 (IO41); also elsewhere on the board
/ESP/SPI_CS_FLASH: U1.6 (IO6); also elsewhere on the board
/ESP/SPI_CS_NET: U1.35 (IO42); also elsewhere on the board
/ESP/SPI_MISO: U1.33 (IO40); also elsewhere on the board
/ESP/SPI_MOSI: U1.32 (IO39); also elsewhere on the board
/ESP/Trigger0: U1.7 (IO7); also elsewhere on the board
/ESP/Trigger1: U1.8 (IO15); also elsewhere on the board
/ESP/Trigger2: U1.9 (IO16); also elsewhere on the board
/ESP/Trigger3: U1.10 (IO17); also elsewhere on the board
/ESP/Turn0: U1.15 (IO3); also elsewhere on the board
/ESP/Turn1: U1.11 (IO18); also elsewhere on the board
/ESP/Turn2: U1.20 (IO12); also elsewhere on the board
/ESP/Turn3: U1.18 (IO10); also elsewhere on the board
/ESP/UART_DTR: Q2.3 (E), R20.1; also elsewhere on the board
/ESP/UART_RTS: Q1.3 (E), R21.1; also elsewhere on the board
/ESP/UART_RX: U1.36 (RXD0); also elsewhere on the board
/ESP/UART_TX: U1.37 (TXD0); also elsewhere on the board
GND: C15.1, C16.1, C17.2, C22.2, C23.2, C24.2, C25.2, C30.2, C31.2, SW2.1, SW3.2, U1.1 (GND), U1.40 (GND), U1.41 (GND); also elsewhere on the board
unnamed: Q1.2 (B), R20.2
unnamed: Q1.1 (C), R18.1
unnamed: Q2.2 (B), R21.2
unnamed: Q2.1 (C), R19.1
unnamed: C16.2, C17.1, R18.2, R22.2, SW3.1, U1.3 (EN)

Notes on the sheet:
SPI Flash
Reset Button
Flash Button
GPIO0 - Boot mode GPIO46 - Boot mode GPIO35-37 - Internal flash/PSRAM GPIO45 - VDD_SPI for flash/PSRAM GPIO3 - JTAG signal source selection Normal GPIOs 1-2 4-7 8 - I2C SDA (convention) 9 - I2C SCL (convention) 10-18 19-20 - USB 21 33-34 38-42 43-44 UART (43-TX, 44-RX) 47-48 45 - Internal pull down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

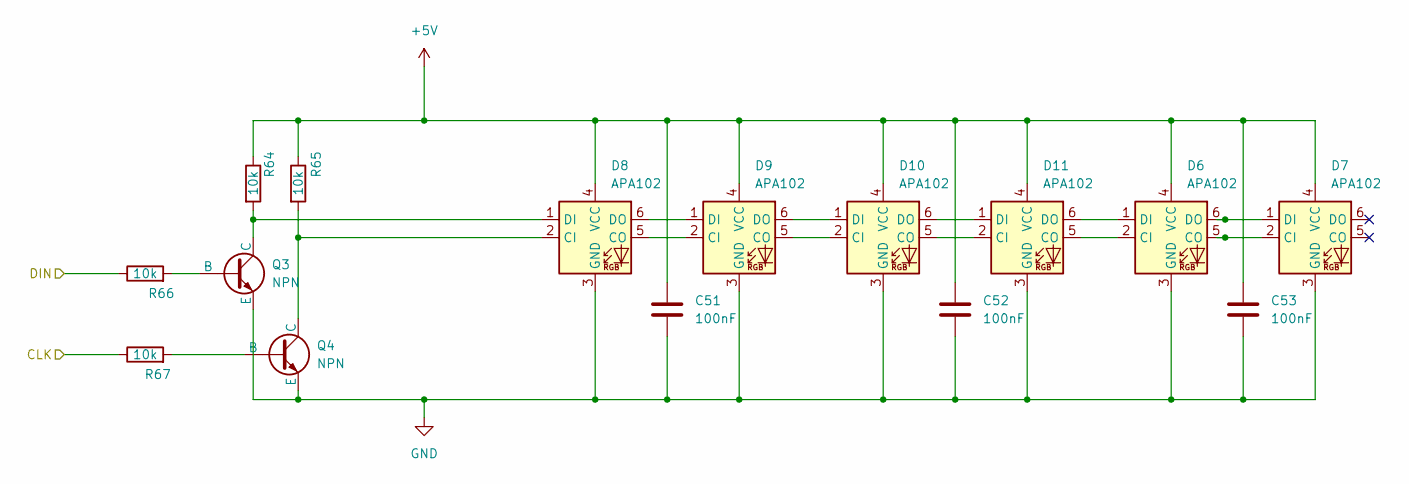
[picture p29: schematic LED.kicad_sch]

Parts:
C51, C52, C53: 100nF; C_0603_1608Metric_Pad1.08x0.95mm_HandSolder
D6, D7, D8, D9, D10, D11: APA102; LED_RGB_5050-6
Q3, Q4: NPN; SOT-23_Handsoldering
R64, R65, R66, R67: 10k; R_0603_1608Metric_Pad0.98x0.95mm_HandSolder

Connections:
+5V: C51.1, C52.1, C53.1, D6.4 (VCC), D7.4 (VCC), D8.4 (VCC), D9.4 (VCC), D10.4 (VCC), D11.4 (VCC), R64.1, R65.1; also elsewhere on the board
/ESP/LED_CLK: R67.1; also elsewhere on the board
/ESP/LED_DATA: R66.1; also elsewhere on the board
GND: C51.2, C52.2, C53.2, D6.3 (GND), D7.3 (GND), D8.3 (GND), D9.3 (GND), D10.3 (GND), D11.3 (GND), Q3.3 (E), Q4.3 (E); also elsewhere on the board
unnamed: D6.5 (CO), D7.2 (CI)
unnamed: D6.6 (DO), D7.1 (DI)
unnamed: D8.2 (CI), Q4.1 (C), R65.2
unnamed: D8.5 (CO), D9.2 (CI)
unnamed: D8.1 (DI), Q3.1 (C), R64.2
unnamed: D8.6 (DO), D9.1 (DI)
unnamed: D9.5 (CO), D10.2 (CI)
unnamed: D10.5 (CO), D11.2 (CI)
unnamed: D9.6 (DO), D10.1 (DI)
unnamed: D10.6 (DO), D11.1 (DI)
unnamed: D6.2 (CI), D11.5 (CO)
unnamed: D6.1 (DI), D11.6 (DO)
unnamed: Q3.2 (B), R66.2
unnamed: Q4.2 (B), R67.2

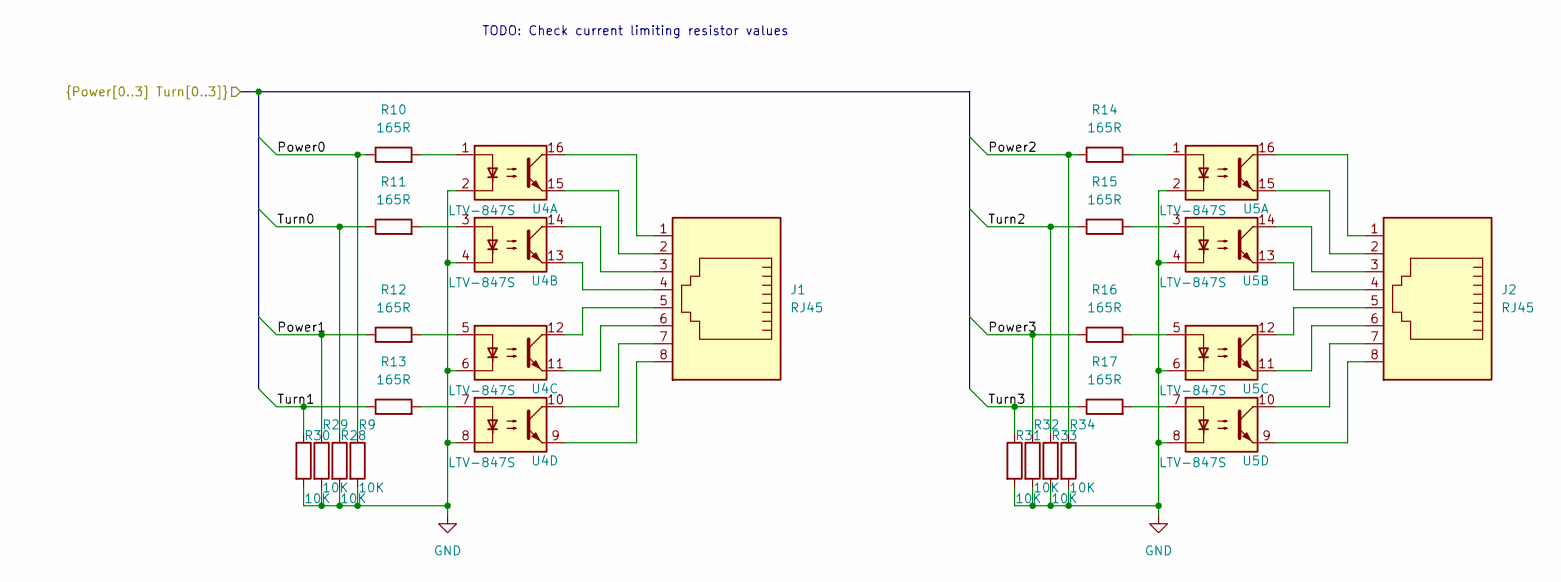
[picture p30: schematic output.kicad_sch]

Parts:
J1, J2: RJ45
R9, R28, R29, R30, R31, R32, R33, R34: 10K; R_0603_1608Metric_Pad0.98x0.95mm_HandSolder
R10, R11, R12, R13, R14, R15, R16, R17: 165R; R_0603_1608Metric_Pad0.98x0.95mm_HandSolder
U4, U5: LTV-847S; SMDIP-16_W9.53mm

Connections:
/ESP/Power0: R9.1, R10.1; also elsewhere on the board
/ESP/Power1: R12.1, R29.1; also elsewhere on the board
/ESP/Power2: R14.1, R34.1; also elsewhere on the board
/ESP/Power3: R16.1, R32.1; also elsewhere on the board
/ESP/Turn0: R11.1, R28.1; also elsewhere on the board
/ESP/Turn1: R13.1, R30.1; also elsewhere on the board
/ESP/Turn2: R15.1, R33.1; also elsewhere on the board
/ESP/Turn3: R17.1, R31.1; also elsewhere on the board
GND: R9.2, R28.2, R29.2, R30.2, R31.2, R32.2, R33.2, R34.2, U4.2, U4.4, U4.6, U4.8, U5.2, U5.4, U5.6, U5.8; also elsewhere on the board
unnamed: J1.1, U4.16
unnamed: J1.2, U4.15
unnamed: J1.3, U4.14
unnamed: J1.4, U4.13
unnamed: J1.5, U4.12
unnamed: J1.6, U4.11
unnamed: J1.7, U4.10
unnamed: J1.8, U4.9
unnamed: J2.1, U5.16
unnamed: J2.2, U5.15
unnamed: J2.3, U5.14
unnamed: J2.4, U5.13
unnamed: J2.5, U5.12
unnamed: J2.6, U5.11
unnamed: J2.7, U5.10
unnamed: J2.8, U5.9
unnamed: R10.2, U4.1
unnamed: R11.2, U4.3
unnamed: R12.2, U4.5
unnamed: R13.2, U4.7
unnamed: R14.2, U5.1
unnamed: R15.2, U5.3
unnamed: R16.2, U5.5
unnamed: R17.2, U5.7

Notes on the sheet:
TODO: Check current limiting resistor values

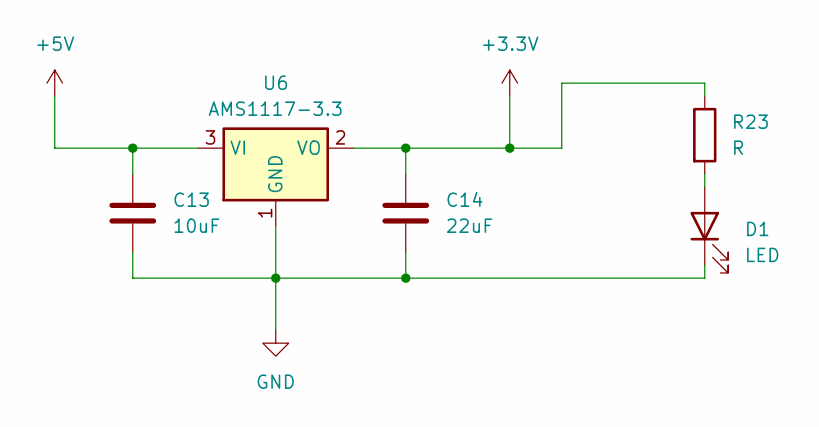
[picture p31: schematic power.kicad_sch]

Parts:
C13: 10uF; C_0603_1608Metric_Pad1.08x0.95mm_HandSolder
C14: 22uF; C_0603_1608Metric_Pad1.08x0.95mm_HandSolder
D1: LED; LED_0603_1608Metric_Pad1.05x0.95mm_HandSolder
R23: R; R_0603_1608Metric_Pad0.98x0.95mm_HandSolder
U6: AMS1117-3.3; SOT-223

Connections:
+3.3V: C14.1, R23.1, U6.2 (VO); also elsewhere on the board
+5V: C13.1, U6.3 (VI); also elsewhere on the board
GND: C13.2, C14.2, D1.1 (K), U6.1 (GND); also elsewhere on the board
unnamed: D1.2 (A), R23.2

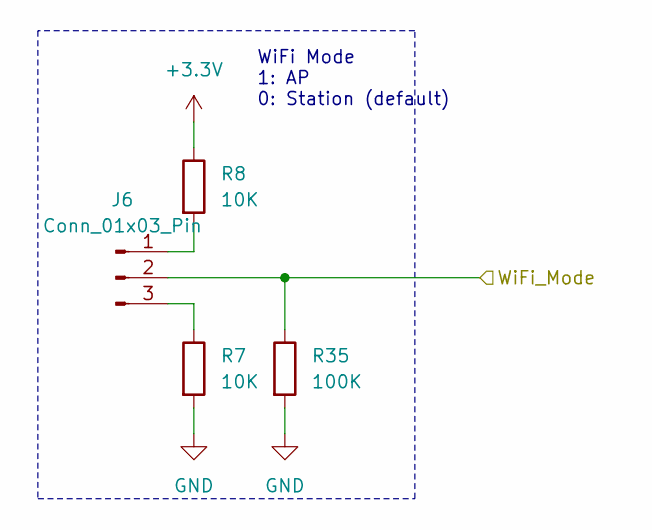
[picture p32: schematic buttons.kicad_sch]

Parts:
J6: Conn_01x03_Pin; PinHeader_1x03_P2.54mm_Vertical
R7, R8: 10K; R_0603_1608Metric_Pad0.98x0.95mm_HandSolder
R35: 100K; R_0603_1608Metric_Pad0.98x0.95mm_HandSolder

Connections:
+3.3V: R8.1; also elsewhere on the board
/Buttons/WiFi_Mode: J6.2, R35.1; also elsewhere on the board
GND: R7.2, R35.2; also elsewhere on the board
unnamed: J6.1, R8.2
unnamed: J6.3, R7.1

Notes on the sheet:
WiFi Mode 1: AP 0: Station (default)

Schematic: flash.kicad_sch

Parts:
C28: 100nF; C_0603_1608Metric_Pad1.08x0.95mm_HandSolder
C29: 10uF; C_0603_1608Metric_Pad1.08x0.95mm_HandSolder
R39: 10K; R_0603_1608Metric_Pad0.98x0.95mm_HandSolder
U8: MX25L3233FM; SOIC-16W_7.5x10.3mm_P1.27mm

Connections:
+3.3V: C28.1, C29.1, R39.1, U8.2 (VCC); also elsewhere on the board
/ESP/SPI_CLK: U8.16 (SCLK); also elsewhere on the board
/ESP/SPI_CS_FLASH: U8.7 (~CS); also elsewhere on the board
/ESP/SPI_MISO: U8.8 (SO/SIO1); also elsewhere on the board
/ESP/SPI_MOSI: U8.15 (SI/SIO0); also elsewhere on the board
GND: C28.2, C29.2, U8.10 (GND); also elsewhere on the board
unnamed: R39.2, U8.1 (~HOLD/SIO3), U8.9 (~WP/SIO2)

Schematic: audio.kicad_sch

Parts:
C1, C2: 2.2uF; C_0603_1608Metric_Pad1.08x0.95mm_HandSolder
C3, C4, C5, C6: 0.1uF; C_0603_1608Metric_Pad1.08x0.95mm_HandSolder
C7, C8, C11, C12: 10uF; C_0603_1608Metric_Pad1.08x0.95mm_HandSolder
C9, C10: 2.2nF; C_0603_1608Metric_Pad1.08x0.95mm_HandSolder
J7: AudioJack4; AudioJack PJ-320A
R5, R6: 470R; R_0603_1608Metric_Pad0.98x0.95mm_HandSolder
R44, R45: 10K; R_0603_1608Metric_Pad0.98x0.95mm_HandSolder
U2: PCM5102A; TSSOP-20_4.4x6.5mm_P0.65mm

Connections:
+3.3V: C6.1, C8.1, R45.1, U2.20 (DVDD); also elsewhere on the board
+3.3VA_Audio: C3.1, C4.1, C11.1, C12.1, U2.1 (CPVDD), U2.8 (AVDD)
/Audio/BCK: U2.13 (BCK); also elsewhere on the board
/Audio/MCLK: U2.12 (SCK); also elsewhere on the board
/Audio/SD: U2.14 (DIN); also elsewhere on the board
/Audio/WS: U2.15 (LRCK); also elsewhere on the board
GND: R44.2; also elsewhere on the board
GNDA: C2.2, C3.2, C4.2, C9.2, C10.2, C11.2, C12.2, J7.R2, J7.S, U2.3 (CPGND), U2.9 (AGND)
unnamed: C9.1, J7.T, R5.2
unnamed: C10.1, J7.R1, R6.2
unnamed: C1.2, U2.4 (CAPM)
unnamed: C1.1, U2.2 (CAPP)
unnamed: R44.1, U2.10 (DEMP), U2.11 (FLT), U2.16 (FMT)
unnamed: C5.1, C6.2, C7.1, C8.2, U2.19 (DGND)
unnamed: C5.2, C7.2, U2.18 (LDOO)
unnamed: R5.1, U2.6 (OUTL)
unnamed: R6.1, U2.7 (OUTR)
unnamed: C2.1, U2.5 (VNEG)
unnamed: R45.2, U2.17 (XSMT)

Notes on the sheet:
TODO: Verify Mode and I2S input

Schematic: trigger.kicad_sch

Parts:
J3: RJ45
R1, R2, R3, R4: 10K; R_0603_1608Metric_Pad0.98x0.95mm_HandSolder
R40: 165R; R_0603_1608Metric_Pad0.98x0.95mm_HandSolder
R41: 250R; R_0603_1608Metric_Pad0.98x0.95mm_HandSolder
R42: 600R; R_0603_1608Metric_Pad0.98x0.95mm_HandSolder
R43: R; R_0603_1608Metric_Pad0.98x0.95mm_HandSolder
U3: LTV-847S; SMDIP-16_W9.53mm

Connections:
+3.3V: R1.1, R2.1, R3.1, R4.1; also elsewhere on the board
/ESP/Trigger0: R1.2, U3.16; also elsewhere on the board
/ESP/Trigger1: R2.2, U3.14; also elsewhere on the board
/ESP/Trigger2: R3.2, U3.12; also elsewhere on the board
/ESP/Trigger3: R4.2, U3.10; also elsewhere on the board
GND: U3.9, U3.11, U3.13, U3.15; also elsewhere on the board
unnamed: J3.1, U3.8
unnamed: J3.2, R43.1
unnamed: J3.3, U3.6
unnamed: J3.4, R42.1
unnamed: J3.5, U3.4
unnamed: J3.6, R41.1
unnamed: J3.7, U3.2
unnamed: J3.8, R40.1
unnamed: R40.2, U3.1
unnamed: R41.2, U3.3
unnamed: R42.2, U3.5
unnamed: R43.2, U3.7

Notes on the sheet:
7-8: 3.3V 5-6: 5.0V 3-4: 12.0V 1-2: ?V

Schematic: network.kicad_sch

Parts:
C34, C38, C39, C40, C41, C42, C43: 100nF; C_0603_1608Metric_Pad1.08x0.95mm_HandSolder
C35, C44: 10uF; C_0603_1608Metric_Pad1.08x0.95mm_HandSolder
C36, C46: 10nF; C_0603_1608Metric_Pad1.08x0.95mm_HandSolder
C37: 4.7uF; C_0603_1608Metric_Pad1.08x0.95mm_HandSolder
C45: 22nF; C_0603_1608Metric_Pad1.08x0.95mm_HandSolder
C47, C48: 6.8nF; C_0603_1608Metric_Pad1.08x0.95mm_HandSolder
C49: 1nF/2kV; C_1206_3216Metric_Pad1.33x1.80mm_HandSolder
L1: L; L_0603_1608Metric_Pad1.05x0.95mm_HandSolder
R48, R49: 10k; R_0603_1608Metric_Pad0.98x0.95mm_HandSolder
R50: 12.4K; R_0603_1608Metric_Pad0.98x0.95mm_HandSolder
R53, R54, R55, R56: 33R; R_0603_1608Metric_Pad0.98x0.95mm_HandSolder
R57, R58, R60, R61: 49R9; R_0603_1608Metric_Pad0.98x0.95mm_HandSolder
R59: 10R; R_0603_1608Metric_Pad0.98x0.95mm_HandSolder
R62, R63: 330R; R_0603_1608Metric_Pad0.98x0.95mm_HandSolder
U10: W5500; LQFP-48_7x7mm_P0.5mm
U11: J0026D21BNL; RJ45_PulseJack_MechB
Y2: 25MHz; Oscillator_SMD_Abracon_ASE-4Pin_3.2x2.5mm

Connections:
+3.3V: C34.1, C35.1, L1.1, R48.1, R49.1, U10.28 (VDD), Y2.4 (Vdd); also elsewhere on the board
+3.3VA_Ethernet: C38.1, C39.1, C40.1, C41.1, C42.1, C43.1, C44.1, L1.2, R57.1, R58.1, R59.1, U10.4 (AVDD), U10.8 (AVDD), U10.11 (AVDD), U10.15 (AVDD), U10.17 (AVDD), U10.21 (AVDD)
/ESP/INT_NET: U10.36 (~INT); also elsewhere on the board
/ESP/SPI_CLK: U10.33 (SCLK); also elsewhere on the board
/ESP/SPI_CS_NET: U10.32 (~SCS); also elsewhere on the board
/ESP/SPI_MISO: U10.34 (MISO); also elsewhere on the board
/ESP/SPI_MOSI: U10.35 (MOSI); also elsewhere on the board
CGND: C49.2, U11.4 (CHS_GND), U11.5 (CHS_GND), U11.SH
GND: C34.2, C35.2, C36.2, C37.2, C38.2, C39.2, C40.2, C41.2, C42.2, C43.2, C44.2, C45.2, C46.2, C49.1, R50.2, U10.3 (AGND), U10.9 (AGND), U10.14 (AGND), U10.16 (AGND), U10.19 (AGND), U10.29 (GND), U10.48 (AGND), U11.10, U11.11, Y2.2 (GND); also elsewhere on the board
unnamed: C47.1, R56.2, R60.1
unnamed: C48.1, R55.2, R61.1
unnamed: R62.1, U11.9
unnamed: R63.1, U11.12
unnamed: C36.1, U10.22 (1V2O)
unnamed: R63.2, U10.27 (ACTLED)
unnamed: R50.1, U10.10 (EXRES1)
unnamed: R62.2, U10.25 (LINKLED)
unnamed: R49.2, U10.43 (PMODE2), U10.44 (PMODE1), U10.45 (PMODE0)
unnamed: R55.1, U10.5 (RXN)
unnamed: R56.1, U10.6 (RXP)
unnamed: C37.1, U10.20 (TOCAP)
unnamed: R53.1, U10.1 (TXN)
unnamed: R54.1, U10.2 (TXP)
unnamed: U10.30 (XI/CLKIN), Y2.3 (OUT)
unnamed: C46.1, R60.2, R61.2, U11.6 (RCT)
unnamed: C47.2, U11.7 (RD+)
unnamed: C48.2, U11.8 (RD-)
unnamed: C45.1, R59.2, U11.3 (TCT)
unnamed: R54.2, R58.2, U11.1 (TD+)
unnamed: R53.2, R57.2, U11.2 (TD-)
unnamed: R48.2, Y2.1 (EN)

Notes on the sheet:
PMODE = 111 10/100Mbps auto-negotiation

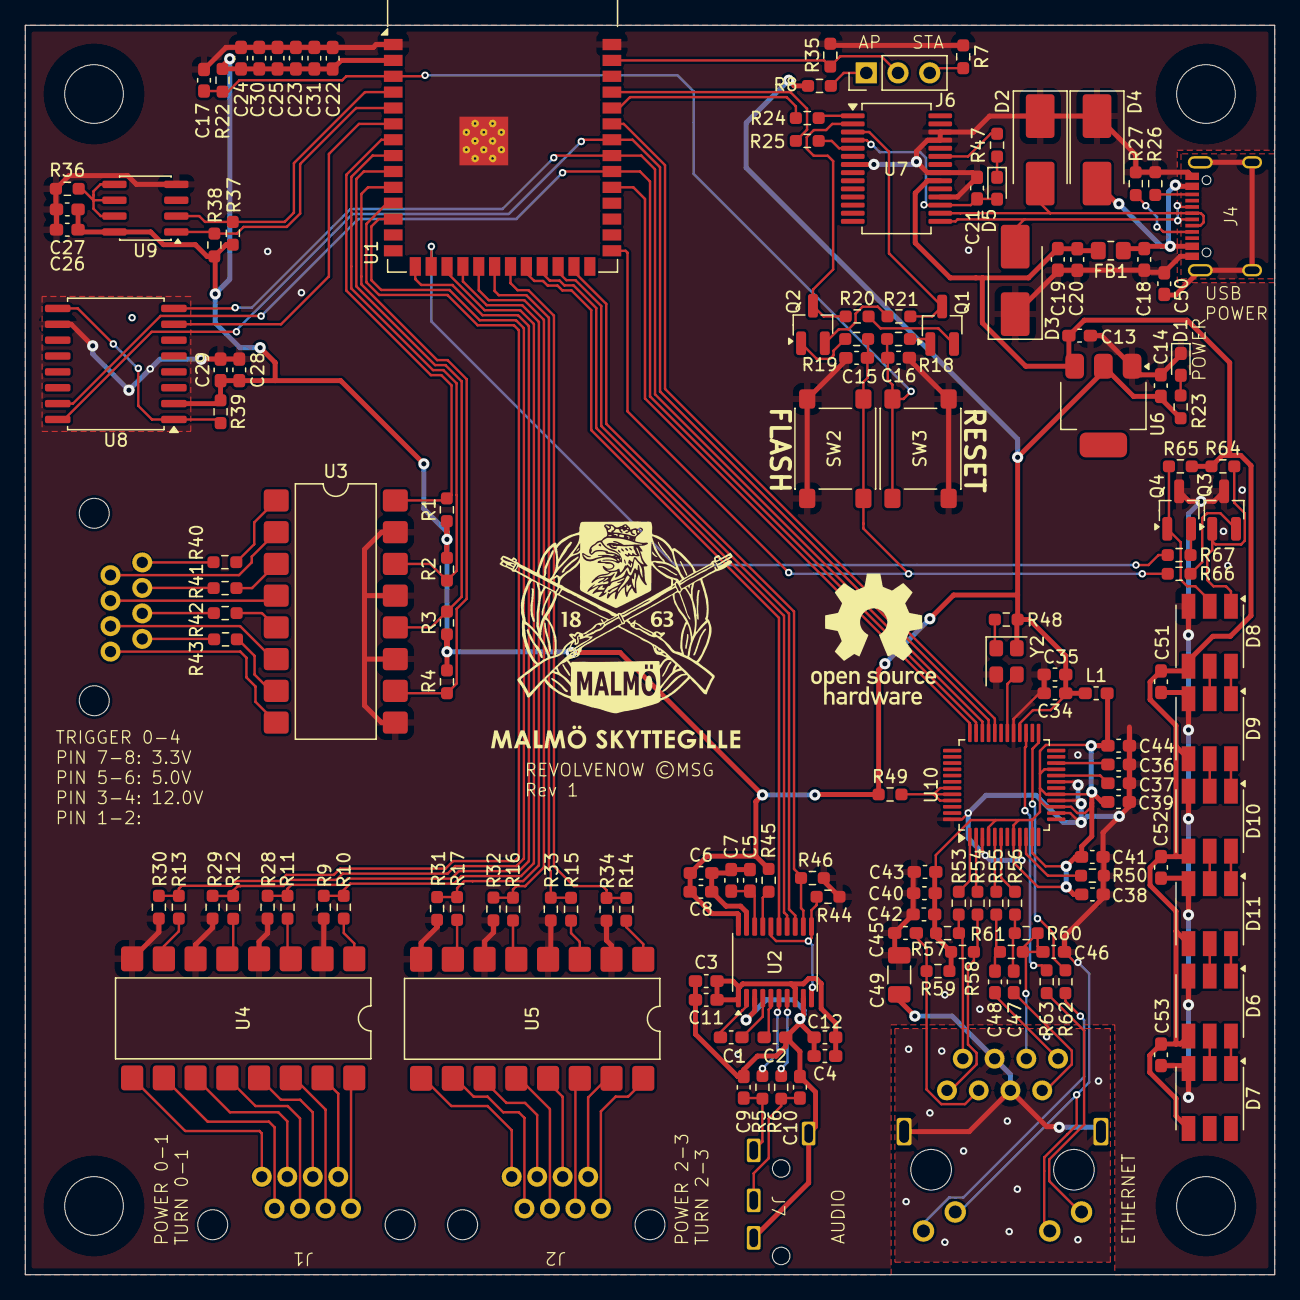
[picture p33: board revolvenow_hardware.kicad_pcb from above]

Board: 2 copper layers, 100.0 x 100.0 mm, 153 parts (0 on the bottom side), 142 nets.

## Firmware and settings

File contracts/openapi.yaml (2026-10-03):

# yaml-language-server: $schema=https://spec.openapis.org/oas/3.1/schema/2022-10-07
---
openapi: 3.1.0

info:
  title: Revolve Now REST API v2
  version: 1.0.0
  license:
    name: MIT
    identifier: MIT
  description: |
    The REST API the Revolve Now firmware serves under `/api/v2`, together
    with the SSE stream at `/sse/v2` (specified separately in
    `contracts/asyncapi.yaml`).

    This document is **canonical** and is written from the implementation
    (`firmware/main/net/web_server.cpp` and `firmware/lib/rt_logic/`), not the
    other way round. Where prose documentation and the firmware disagree, the
    firmware wins and this file follows it. See `contracts/README.md`.

    ## State model

    There is no `GET /status`. Run state is published only over `/sse/v2`: a
    client connects, immediately receives a full `stateUpdate`, and receives
    another after every mutation. The mutating endpoints here answer with a
    short confirmation message, not with state.

    ## Errors

    Every failure is an **RFC 9457 problem detail** served as
    `application/problem+json` (D-19):

    ```json
    {
      "type": "/problems/program_readonly",
      "title": "Program is read-only",
      "status": 409,
      "detail": "Program is read-only and cannot be deleted"
    }
    ```

    `type` is the discriminator — a **stable relative URI that is never
    dereferenced**, and the only member a client should branch on. `title` is
    short and identical for every occurrence of a type; `detail` describes the
    one occurrence and is the string to show a user. `instance` is omitted:
    it identifies a single occurrence and the device has no request ids.

    One status per `type`, always — so the `type` lists under each operation
    below say exactly what a given status code can mean there.

    The slug vocabulary is **shared with the SSE `backend_issue` codes** in
    `contracts/asyncapi.yaml`: a program that will not parse is
    `/problems/program_invalid` over REST and `program_invalid` over SSE,
    because it is the same failure. The full list is the `enum` on
    `Problem.type`.

    A client must tolerate a `type` it does not recognise — fall back to
    `status` and show `detail`. New types are additive.

    ## Authentication

    The control lock is off after every boot and lives in RAM only. While it is
    off,
    **every endpoint is unauthenticated**, including the ones marked as
    requiring a session below. A client turns protection on with
    `POST /api/v2/control-lock/enable`, choosing the password in that call.

    While the lock is on, the protected endpoints accept either credential:

    - `Authorization: Bearer <token>`
    - `Cookie: control_lock=<token>`

    The header is checked first; the cookie is the fallback. Tokens are 16
    random bytes, hex-encoded, valid for 12 hours from issue, and at most 8
    are held at once (oldest evicted first). `enable` and `login` return the
    token in the body *and* set it as
    `Set-Cookie: control_lock=<token>; Path=/; SameSite=Lax` — deliberately not
    `HttpOnly`, because the webapp reads it back. `SameSite=Lax` means the
    cookie only rides along when the webapp is served from the device itself;
    a webapp on another origin authenticates with the bearer token.

    Because of the "off means open" rule, each protected operation lists an
    empty security requirement alongside the two credentials: with the lock
    disabled, a call with no credentials succeeds.

    ## CORS

    The firmware answers credentialed cross-origin requests against an
    allowlist rather than with `*` (a browser refuses a wildcard on a
    credentialed request). An `Origin` header is echoed back in
    `Access-Control-Allow-Origin`, with `Access-Control-Allow-Credentials:
    true`, `Access-Control-Allow-Methods: GET, POST, PUT, DELETE, OPTIONS`,
    `Access-Control-Allow-Headers: Authorization, Content-Type`,
    `Access-Control-Max-Age: 600` and `Vary: Origin`, only when it is one of:

    - `http(s)://<CONFIG_RT_HOSTNAME>.local` (default `revolve-now.local`)
    - `http(s)://<the device's current IP>`
    - `CONFIG_RT_DEV_ORIGIN`, when that Kconfig value is non-empty

    Any other origin gets no CORS headers at all, so the browser blocks the
    response.

    ## Routes that exist but are not modelled as paths here

    Both are catch-alls that would have to be attached to every path to be
    modelled honestly, so they are recorded here instead:

    - `OPTIONS /*` — a single catch-all preflight handler answering `204` with
      no body (with the CORS headers above when the origin is allowed).
      Registered because nothing else answers `OPTIONS`, and a preflight that
      404s fails the real request behind it.
    - `GET /*` — the built webapp, served from the LittleFS path
      `/storage/webapp/` with `index.html` as the default file. Registered
      last so it can never shadow an API route.
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

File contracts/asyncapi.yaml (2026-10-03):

# yaml-language-server: $schema=https://raw.githubusercontent.com/asyncapi/spec-json-schemas/refs/heads/master/schemas/3.1.0.json
---
asyncapi: 3.1.0

info:
  title: Revolve Now SSE v2
  version: 1.0.0
  license:
    name: MIT
  description: |
    The Server-Sent Events stream the Revolve Now firmware serves at
    `/sse/v2`, alongside the REST API specified in `contracts/openapi.yaml`.

    This document is **canonical** and is written from the implementation
    (`firmware/main/net/sse_hub.cpp` and
    `firmware/lib/rt_logic/program_state.h`). See `contracts/README.md`.

    ## Why the stream exists

    There is no `GET /status` in API v2. `stateUpdate` is the only channel run
    state is published on, and it is the reason no status endpoint is needed:
    a client connects, is sent the full current state immediately, and is sent
    it again after every change.

    `backend_issue` covers the other direction: a failure the device noticed
    on its own, which no REST response can carry because no client asked for
    it. A clip that will not play and a program file that will not parse are
    both invisible to a client otherwise — the run simply carries on, quietly
    wrong.

    `libraryChanged` covers the third: the stored programs and audio clips are
    fetched over REST, not published here, so a client that did not make the
    change had no way to learn of it. On a range with a laptop and a phone
    both open, the second one showed a stale list until somebody reloaded it.

    ## Connection behaviour

    - `GET /sse/v2` answers `200` with `Content-Type: text/event-stream`,
      `Cache-Control: no-cache` and `Connection: keep-alive`. The CORS
      headers described in the OpenAPI document apply here too.
    - On connect, before anything else, the server sends one `stateUpdate`
      carrying the full current state, with `retry: 500` — so a browser
      `EventSource` reconnects half a second after a drop. Later frames carry
      no `retry`.
    - Every frame carries an `id:` field: the device's uptime in
      milliseconds. It is a monotonic ordering hint, not a resumption cursor
      — a client's `Last-Event-ID` is read on reconnect but nothing is
      replayed from it, and the fresh `stateUpdate` on connect makes replay
      unnecessary.
    - A `heartbeat` follows every 10 seconds
      (`kSseHeartbeatSeconds`, `firmware/main/config.h`), whether or not
      anything changed.
    - `libraryChanged` is emitted when a REST call changes what
      `GET /api/v2/programs` or `GET /api/v2/audios` would return, and is
      **fire-and-forget** on the same terms as `backend_issue` below: nothing
      is buffered for a client that connects later and nothing is replayed on
      reconnect. A client that was not listening does not need it — it fetches
      both lists on connect anyway.
    - `backend_issue` is emitted only when something fails, and is
      **fire-and-forget**: it is delivered to whoever is connected at that
      instant and to nobody else. Nothing is buffered for a client that
      connects later, nothing is replayed on reconnect, and there is no
      endpoint that lists past issues. A client that was not listening did
      not hear it — the device log is the record, the event is the
      notification. Issues raised during boot, before the HTTP server
      exists, reach no client on this stream at all; those are kept instead
      and served by `GET /api/v2/diagnostics/info` as `startupIssues`, the
      one exception to "no endpoint lists past issues".
    - The stream is one-way and public: no credential is required, and
      nothing a client sends on it is read.

    ## Delivery guarantees

    State is serialized *and* queued under a single lock, and the frames are
    then written from the HTTP task, so the order clients see is the order the
    state actually took. While the HTTP task is busy — serving a firmware
    upload, say — frames wait for it rather than block the run loop. A newer
    `stateUpdate`, `configWindow` or `heartbeat` supersedes a waiting one of
    the same event, so a client may miss an intermediate state or beat but
    receives the latest within one heartbeat of the task freeing up.
    `backend_issue` and `libraryChanged` each count, so they wait up to a
    bound, past which they are **dropped**.

    Dead clients are reaped on the heartbeat cadence: a peer that closed
    cleanly is detected by a non-destructive peek, and TCP keepalive
    (30 s idle, 10 s interval, 3 probes) catches a peer that vanished without
    a FIN.

    A client that is connected but not reading — a backgrounded tab, a phone
    walking out of range — is closed once its socket cannot take a whole frame,
    rather than waited for. Run state survives that, because a reconnect starts
    with a full `stateUpdate`; one-off events sent in between (`libraryChanged`,
    `configWindow`, `backend_issue`) are not replayed, as after any reconnect.

    ## Sockets
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

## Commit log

2026-10-03 docs: refresh the screenshots, and regenerate them with one command (#415)
    * docs(webapp): regenerate the docs screenshots with one command
    `npm run screenshots` drives the app against the mock server and writes
    docs/site/img/, so no board is needed and the images can follow the UI
    instead of drifting. The mock is seeded to look like a board on a club
    network (a LAN address, a firmware version matching the bundle, served
    as rotation-target.local) so none of the dev-server artefacts reach the
    docs.
    The dev-server mock plugin takes an optional factory so the script can
    seed it and keep a handle on it; the dev server itself is unchanged.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
2026-10-03 fix(firmware): drop an SSE client that stops reading instead of waiting on it (#426)
    * fix(firmware): drop an SSE client that stops reading instead of waiting on it
    PsychicEventSourceClient::sendEvent retries a send that times out forever,
    on the httpd task. One client still connected but not reading - a
    backgrounded tab, a phone at the edge of range - filled its socket after
    about 52 frames and then wedged the whole web server, REST included, until
    it went away. Reproduced on a bench board with one SSE client holding a
    tiny receive window.
    Fan-out now writes each frame with MSG_DONTWAIT and closes any client that
    cannot take it whole. Nothing is lost: every stateUpdate is the full state
    a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
    [asyncapi.yaml, openapi.yaml]
2026-10-03 fix(ota): put the upload behind the control lock, and test its answers (#423)
    * fix(ota): put the upload behind the control lock, and test its answers
    POST /api/v2/ota was registered with no control-lock check, so with the
    lock on anyone on the network could still flash firmware - the contract
    declared a 401 the device never sent. It now runs require_control_lock
    in a middleware, before any of the body is streamed to flash.
    The handler's decisions move into rt::ota::UploadSession (rt_logic),
    where a host test drives them in the order the callbacks reach them.
    Per-request state is reset in the middleware, the one place every
    request passes, rather than in onUpload, which an empty file part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
    [asyncapi.yaml, openapi.yaml]
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2026-10-03 fix(firmware): keep SSE frames out of the httpd mailbox so none are lost (#431)
    * fix(firmware): keep SSE frames out of the httpd mailbox so none are lost
    httpd_queue_work posts to a six-datagram loopback mailbox that drops a
    message without an error when full. One message per frame therefore lost
    frames silently while the httpd task was busy - an OTA upload during a
    run - and leaked each one. The loss that mattered was the last
    stateUpdate, leaving every client on a stale strip.
    Frames now wait in rt::SseOutbox, and the mailbox carries only a drain
    message: one when the outbox goes from empty to non-empty, plus one per
    heartbeat that also reaps dead clients. stateUpdate, configWindow and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
    [asyncapi.yaml]
2026-10-03 fix(firmware): move boards off the stored pre-rename hostname (#440)
    Saving any hardware setting writes the hostname with it, so a board
    configured before the rename has rotation-target in NVS whether or not
    anyone chose it, and kept answering at rotation-target.local after
    updating. The overlay now reads that one value as unset, so the board
    takes this build's default; the next save overwrites it. Any other
    stored hostname is kept.
    D-44's consequence paragraph claimed only an explicit hostname change
    stored it; corrected.
    [test_hardware_overlay.cpp]
2026-10-03 feat: give Revolve Now a logo and favicon (#442)
    * feat: give Revolve Now a logo and favicon
    The tab icon was the club's logo, and the docs used Material's default.
    The symbol is one target plate face-on, half-turned and edge-on, turning
    counter-clockwise seen from above; the logo sets it beside "RevolveNow" in
    Barlow Semi Condensed, outlined so no font is needed.
    - Web app and program editor: SVG favicon that follows the OS theme, an
    ICO fallback and an iOS home-screen icon. The logo replaces the plain
    name in Settings > About and leads the editor's heading.
    - Docs: the symbol in the header and as the favicon, the logo on the home
    page as a light/dark pair that follows the site's ow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
2026-10-04 docs: point ESP-IDF version prose at idf_component.yml (#484)
    CONTRIBUTING.md, firmware/AGENTS.md, firmware/CONTRIBUTING.md,
    firmware/docs/QEMU.md, two helper scripts and three workflow comments
    still named v6.0.2 (or a hand-copied v6.1) after the toolchain moved.
    They now point at the `idf:` pin in firmware/main/idf_component.yml,
    which the component manager enforces, instead of repeating it. That
    manifest's own comment drops the prose copy from its list of places the
    version is written, and its container count is corrected from "three
    jobs, two files" to six jobs in four files.
    Refs #453
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2026-10-04 ci: replace the release-bump check with a breaking-footer check (#475)
    The git-cliff comparison could not tell a breaking footer from a plain
    feat below 1.0, and anything already on main since the last tag masked
    the title's own bump, so it passed every case. The job now fails a PR
    whose branch commits carry a breaking footer while the title has no
    '!', which holds at every version and needs no git-cliff.
    The grep is shared with contracts.yml's breaking-change step as
    .github/scripts/check_breaking_marker.sh. The job keeps its name.
    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
2026-10-04 test(tooling): pytest for pack_assets, wav_to_adpcm and the workflow-permissions checker (#478)
    - pack_assets: round trip (empty file, gz mount, C escapes, sentinel,
    alignment, determinism, no rewrite of unchanged outputs), read back the
    way embedded_fs.cpp reads the index and blob.
    - wav_to_adpcm: a Python port of rt::decode_ima_adpcm_block, proven on the
    ffmpeg vector host_test pins, then used to check that the decoder lands
    exactly on the encoder's predictor track and that the reconstruction is
    close to the input; plus a transcoded WAV decoded through its own headers.
    - check_workflow_permissions: passing and failing fixture trees, read-all /
    write-all, a missing grant, and th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
2026-10-04 test(e2e): restore targets between specs and assert them after stop, reset, skip and completion (#481)
    resetDevice() now ends with POST /targets/show, so no spec depends on
    ota.spec.ts sorting first to put the targets back. A new spec runs an
    uploaded two-series program to completion and asserts the strip and the
    device's programState after completion, reset and skip_to (D-31); run.spec's
    first test asserts the strip is unchanged by a stop, and run.test.tsx covers
    the Reset button against the mock.
    Drops the permanent test.skip, the 7 s sleep in the #95 test, and three e2e
    tests that duplicated mock-backed unit tests; the unload test keeps only the
    device's own 409 and its idempotent 200. B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
2026-10-04 fix(contracts): document what the firmware actually answers (#466)
    - Uploaded programs and clips are numbered from 1000 (kFirstUploadId),
    not 100.
    - POST /config/hardware/reset answers 403 hardware_config_window_closed
    and 409 program_running, like the PUT.
    - POST /programs/start answers 409 program_running during an OTA, and
    checks the body's id before whether anything is loaded.
    - POST /ota declares the control-lock security it is gated on.
    - The webapp is served from /embedded/webapp/, with an SPA fallback for
    page-like GETs; the data partition is userdata; asyncapi example paths
    follow suit; the "contract version 3.0.0" references point at D-16.
    - The server-wide body cap is 4.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
    [asyncapi.yaml, openapi.yaml]
2026-10-04 refactor(contracts): collapse duplicated problem responses into components (#472)
    The 42 inline application/problem+json responses were structurally
    identical. They now $ref a shared components/responses/Problem, and each
    keeps its own description beside the $ref, which OpenAPI 3.1 allows.
    The {status, restarting} body of POST /system/restart and POST /ota is
    one RestartAccepted schema. It has additionalProperties: false, which
    only one copy had: both firmware paths send exactly those two fields.
    Refs #456
    [openapi.yaml]
2026-10-04 fix(firmware): answer a failed program write with 500, not 400 (#491)
    * fix(firmware): answer a failed program write with 500, not 400
    POST /programs returned 400 program_invalid both for a document the
    parser refused and for a valid document the device could not write to
    flash. The second is the device's failure: a 400 tells the operator to
    fix a file that is fine. add_uploaded() now reports the two apart and a
    write failure is 500 program_store_failed, as PUT already answers it.
    The contract gains the 500, an additive change.
    * refactor(contracts): use the shared problem response for the new 500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
    [openapi.yaml]
2026-10-04 refactor(webapp): remove dead API code and unused dependencies (#471)
    Remove the unused control-lock fetch helpers, programsApi, client(),
    useClient and initializeBaseUrl; drop @tanstack/router-core, csstype,
    ts-node and scripts/zip-dist.ts. Give the base URL one owner (main.tsx),
    reuse downloadJson in ProgramDetails, share BANK_LETTERS, stop logging
    every SSE frame, and let the run page load a program with id 0.
    Tests: fix the troubleshooting-section false pass, restore
    scrollIntoView in Timeline.test.tsx, share enableControlLockElsewhere,
    and drop stale port comments.
    Refs #459
2026-10-04 fix(firmware): write audios.json atomically (#473)
    The upload index was rewritten in place, so a power cut mid-write lost
    the index of every uploaded clip. Stage it to audios.json.tmp and rename
    it into place, as programs::write_program already does.
    Part of #457.
2026-10-04 fix(firmware): stop DELETE /audios from blocking on a playing clip (#474)
    audio::is_playing() read s_playing under the I2S lock, which play_one()
    holds for the whole clip, so DELETE /audios/{id} parked the httpd task -
    and with it every SSE drain - until the clip ended, while also holding
    the audios map lock the run loop needs.
    s_playing now has its own mutex, held only for a compare or an
    assignment. is_playing() becomes run_unless_playing(path, fn), which runs
    the unlink under that mutex, and the playback task claims a clip before
    opening it, so a clip cannot be opened between the check and the unlink.
    The I2S lock still serialises the channel, unchanged.
    Part of #457.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
    [audio.cpp]
2026-10-04 fix(firmware): stop where the run is, not at the last published frame (#469)
    stop() cleared the run anchor without capturing elapsed time, so ticker_ms
    kept the last published frame - up to a second back, often an event
    boundary - and start() resumed from there. A pause just after a boundary
    resumed onto it at offset 0 and replayed that event's audio; the comment
    in start() promised the opposite.
    stop() now captures elapsed, capped at the end of the event that was
    entered: after a late wake-up elapsed can already sit in the next event,
    and resuming mid-way into it would skip its audio, while resuming onto
    the boundary enters it once.
    The mock server mirrors it.
    Closes #450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
2026-10-04 refactor(firmware): remove dead constants and duplicated helpers in main/ (#486)
    - config.h: drop the pin, polarity and port constants nothing reads
    (kTargetPin, kTargetLevelShown/Hidden, kRgbLedPin, kI2sPort,
    kI2sBck/Lck/DinPin, kHttpPort) - hardware_store owns all of those - with
    the driver includes they needed and a banner that still said every pin
    was a menuconfig setting. Seven files included config.h for nothing.
    - storage::nvs_read_str replaces wifi_store's read_key and
    hardware_store's read_str, which were the same function.
    - net_common holds the IP record, net_mgr::ip_address() and start_mdns()
    that wifi_mgr and eth_mgr each carried a copy of.
    - web_server: refuse_if_ru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
    [audio.cpp]
2026-10-05 docs(contracts): check Program/Series/Event against the program schema, document HTTP-layer failures (#493)
    * docs(contracts): check Program/Series/Event against the program schema, document HTTP-layer failures
    Program, Series and Event are declared in openapi.yaml and in
    program.schema.json. A $ref from one to the other was tried and rejected:
    openapi-typescript inlines the $defs into Program and makes every defaulted
    field required, so generated.d.ts changes meaning. check_program_schema.py
    compares field names, required, enums, minimum and additionalProperties
    instead and runs from validate.sh.
    Also document the failures raised below the handlers that leak past
    problem+json: a multipart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
    [openapi.yaml]
2026-10-05 fix(firmware): enter every event a late wake-up crossed, not just the one the clock is in (#495)
    tick() entered only the event elapsed_ms fell in, so an event crossed entirely
    between two wake-ups never fired its target command or audio: a 1 ms hide
    skipped on a wake-up 1 ms late. It now enters every event after the current one
    up to the located index, in order, and does the same on the tick that finds the
    series over, so a final hide cannot be lost. kMinEventMs stays 1 and no contract
    changes. Targets are a level write and audio keeps one waiting clip, so a replay
    settles on the declared state without a burst.
    The host harness advanced the clock by exactly what tick() asked for, which is
    w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
2026-10-05 fix(firmware): stop PsychicHttp body readers spinning when the peer closes mid-body (#494)
    * fix(firmware): stop PsychicHttp body readers spinning when the peer closes mid-body
    httpd_req_recv() returns 0 on a peer FIN. loadBody() and
    MultipartProcessor::process() handled only TIMEOUT and FAIL, so remaining never
    shrank and the httpd task spun until the TWDT panicked the device. loadBody()
    also overwrote a failed read's ESP_FAIL with ESP_OK. Treat any other <= 0 as a
    failure in both, record the patch in lib/psychic_http/CMakeLists.txt the way
    lib/dns_server does, and amend the AGENTS.md sentence that called dns_server
    the only exception.
    Fixes #448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
2026-10-05 refactor(webapp): share IssueList and move the timeline anchor helpers into run-position (#504)
    * refactor(webapp): share IssueList and move the timeline anchor helpers into run-position
    The warnings <ul> was copied into ProgramEditor (twice), the programs route and
    the standalone editor; it is one IssueList now. anchorMs, anchorRelativeMs,
    anchorRelativeSeconds, formatRunClock and formatSeconds mirror
    rt::Series::timer_anchor_ms, which by this repository's own rule puts them in
    lib/ beside run-position, with the unit tests they never had.
    Refs #460
    * style(webapp): prettier on Timeline imports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
2026-10-05 fix(firmware): allow GPIO3 as a target bank pin (#513)
    GPIO3 is a strapping pin only for the JTAG signal source, and only once
    EFUSE_STRAP_JTAG_SEL is burned, so driving it cannot stop the chip
    booting the way GPIO0 or GPIO45 can. The validator refused it with that
    reason anyway, which made the PCB rev 1 unconfigurable: it routes Turn0
    to GPIO3, and no hardware config could be saved while bank A was on it.
    Closes #505
    [test_hardware_config.cpp]
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2026-10-06 fix(ci): put esptool on PATH in the release staging step (#517)
    The first real 0.1.0 run (37431533808) failed in "Stage and checksum the
    images" with `esptool: command not found`: each step is a fresh shell, and
    only the build step sourced the IDF environment. Nothing was tagged or
    published.
    Refs #265
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2026-10-06 feat: back up and restore a device's uploads and settings (#521)
    * feat: back up and restore a device's uploads and settings (#520)
    GET /api/v2/backup streams one stored ZIP of what a club has put on a
    board: uploaded programs and clips, and the hardware configuration as
    overrides of the compiled defaults. POST /api/v2/restore reads it back
    as it arrives, applying each item through the checks an upload gets.
    A restore only adds. Clips and programs take new ids, programs have
    their audio_ids rewritten to the restored clips, and anything identical
    to an upload already present is skipped, so restoring twice changes
    nothing. Hardware needs the configuration window and is skipped and
    reported w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
    [openapi.yaml]
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2026-10-06 docs: describe the audio pins and MCLK, and stop saying a reflash loses uploads (#526)
    Expert mode's Audio group (BCK, WS, DOUT and the MCLK pin from #511) had no
    page; the PCB rev 1 needs MCLK, and a missing one hides until a power cut.
    Uploads survive updates since #227 and move with a backup since #521.
    Closes #523
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2026-10-06 feat: put a backup's manifest, hardware and clip titles in one backup.json with a JSON Schema (#527)
    * feat: put a backup's manifest, hardware and clip titles in one backup.json with a JSON Schema
    The backup ZIP started with three small documents: manifest.json,
    hardware.json and audio/index.json. They are now one backup.json, described
    by contracts/backup.schema.json, so the format is versioned and checked as a
    single document. Clips stay audio/<id>.wav and programs programs/<id>.json.
    The hardware part of the schema is HardwareConfigPatch written out;
    check_backup_schema.py fails when the two drift. The contract suite checks
    GET /backup's backup.json against the schema, on the mock and o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
    [openapi.yaml]
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2026-10-07 revert: take the unverified PCBA board line back out of main (#522) (#536)
    This reverts commit aa257bf9a9a88d249b63789ae22e7ba59ac2d471.
    #522 was an exploration of whether a fully assembled JLCPCB board is
    doable and what it would cost. The parts list and D-49 are unverified on
    any board and were not meant to land. It also removes the hand-built rev 1
    sources it carried, which belong to #436, still open.
    The exploration reopens as a draft pull request.
    [LED.kicad_sch, audio.kicad_sch, buttons.kicad_sch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]
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2026-10-28 fix(firmware): bound the WAV sample rate to 8-192 kHz (#639)
    parse_wav_header refused only a zero rate. IDF's I2S clock setup computes
    rate * 256 in uint32_t, so a declared rate that is a multiple of 2^24 wraps
    to zero and is then used as a divisor when the clip is played. Refusing
    anything outside 8-192 kHz at parse time closes it for upload, restore and
    playback alike, since all three go through the same parser.
    Every shipped clip is 24 or 44.1 kHz and the web app converts uploads to
    24 kHz, so no real input is affected.
2026-10-28 fix(firmware): bound how long a request body may take (#641)
    PsychicHttp's three body readers (PsychicRequest::loadBody,
    MultipartProcessor and PsychicUploadHandler) retried a recv timeout with
    no limit. The body is read on the only httpd task, before the route's
    lock check, so a peer that sent headers with a Content-Length and then
    nothing held every other request off - including programs/stop - for as
    long as its socket stayed open.
    After a 10 s grace period a body now has to keep up 8 KiB/s on average,
    or the read fails. Counting time against bytes received, rather than
    consecutive timeouts, also bounds a peer that drips a byte at a time.
    PsychicUploadHandler also gains the FIN handling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
2026-10-28 fix(firmware): bind the setup portal's BOOT press to one submission (#642)
    * fix(firmware): bind the setup portal's BOOT press to one submission
    The portal took a press as the first step: any short press set a
    device-wide flag, and whichever POST /save arrived next consumed it. The
    setup AP's password is public, so anyone in range could poll /save with
    their own network and take the press the operator made for theirs.
    The press is now the last step. /save stages the submission and asks for
    a press; the press commits it only if no different submission arrived
    alongside it (rt::SetupClaim, host-tested). A second party polling with
    their own credentials now turns the press into a conflict tha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
2026-10-28 fix(webapp): end the device session on Log out (#648)
    Log out only removed the token from localStorage. The device never
    heard about it, so the token stayed valid until it expired, and the
    control_lock cookie - which the device prefers to nothing - kept
    authorising the browser. On a shared range laptop, Log out left the next
    person holding the lock.
    It now calls POST /control-lock/logout, which the firmware already had,
    and drops the local token afterwards whether or not the device answered.
    The mock server gains the route, mirroring the firmware: not itself
    protected, always 200, bearer token first and then the cookie.
2026-10-28 fix(firmware): refuse GPIO33 and GPIO34 with the other octal PSRAM pins (#643)
    In octal mode the N16R8's PSRAM uses GPIO33-37 (SPIIO4-7 and SPIDQS),
    but gpio_is_reserved refused only 35-37. A saved configuration naming 33
    or 34 passed validation, including the revalidation at boot that exists
    to fall back to the compiled defaults, and gpio_config() then moved the
    pad off its PSRAM function.
    The reserved range is 33-37 in the firmware, the mock server, the
    contract, the web app's text and the hardware docs. A device that already
    stores 33 or 34 now fails revalidation at boot and falls back to the
    compiled defaults, which is what that fallback is for.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
2026-10-28 fix(firmware): bound the series, events and clips in a program (#645)
    parse_program set no limit on how many series a program has, how many
    events a series has or how many clips an event starts; the 1 MiB body cap
    was the only bound. Every stored program is parsed into RAM at boot,
    before the network is up, so one upload of ~34,000 one-millisecond events
    held as many heap blocks from then on.
    A program now has at most 64 series, a series 128 events and an event 8
    clips (the shipped programs peak at 19, 15 and 3). 128 events is also what
    makes the int32 total-duration argument in program.h hold. The schema
    carries the same ceilings as maxItems, and the web app's document reader
    and the mock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
2026-10-28 fix(firmware): cap request bodies at 1 MiB and parameters at 32 (#644)
    maxRequestBodySize was the firmware slot, 4.5 MiB, but it only bounds
    bodies PsychicWebHandler reads whole into RAM before the route callback
    and its lock check: OTA, restore and audio stream through upload handlers
    and are bounded by maxUploadSize. No callback route takes more than a
    program document, so the cap is now kMaxUploadBytes.
    Nothing limited how many parameters a request carried either. Each is a
    heap object, so a form-urlencoded body of '&' cost about 70 bytes of
    heap per byte sent. PsychicRequest::addParam now drops parameters past
    PSYCHIC_MAX_PARAMS (32), as a fourth local patch on PsychicHttp.
    Signed-off-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

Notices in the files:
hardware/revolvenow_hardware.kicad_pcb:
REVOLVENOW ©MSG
